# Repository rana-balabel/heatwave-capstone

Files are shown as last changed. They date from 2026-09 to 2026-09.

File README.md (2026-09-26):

# HeatWave 🔥

**AI-Powered Heatstroke Prediction Wearable**

University of Waterloo Engineering Capstone Design Project.

HeatWave is a wearable embedded system designed to assess heatstroke
risk using physiological and environmental sensor data.

## Capstone Poster

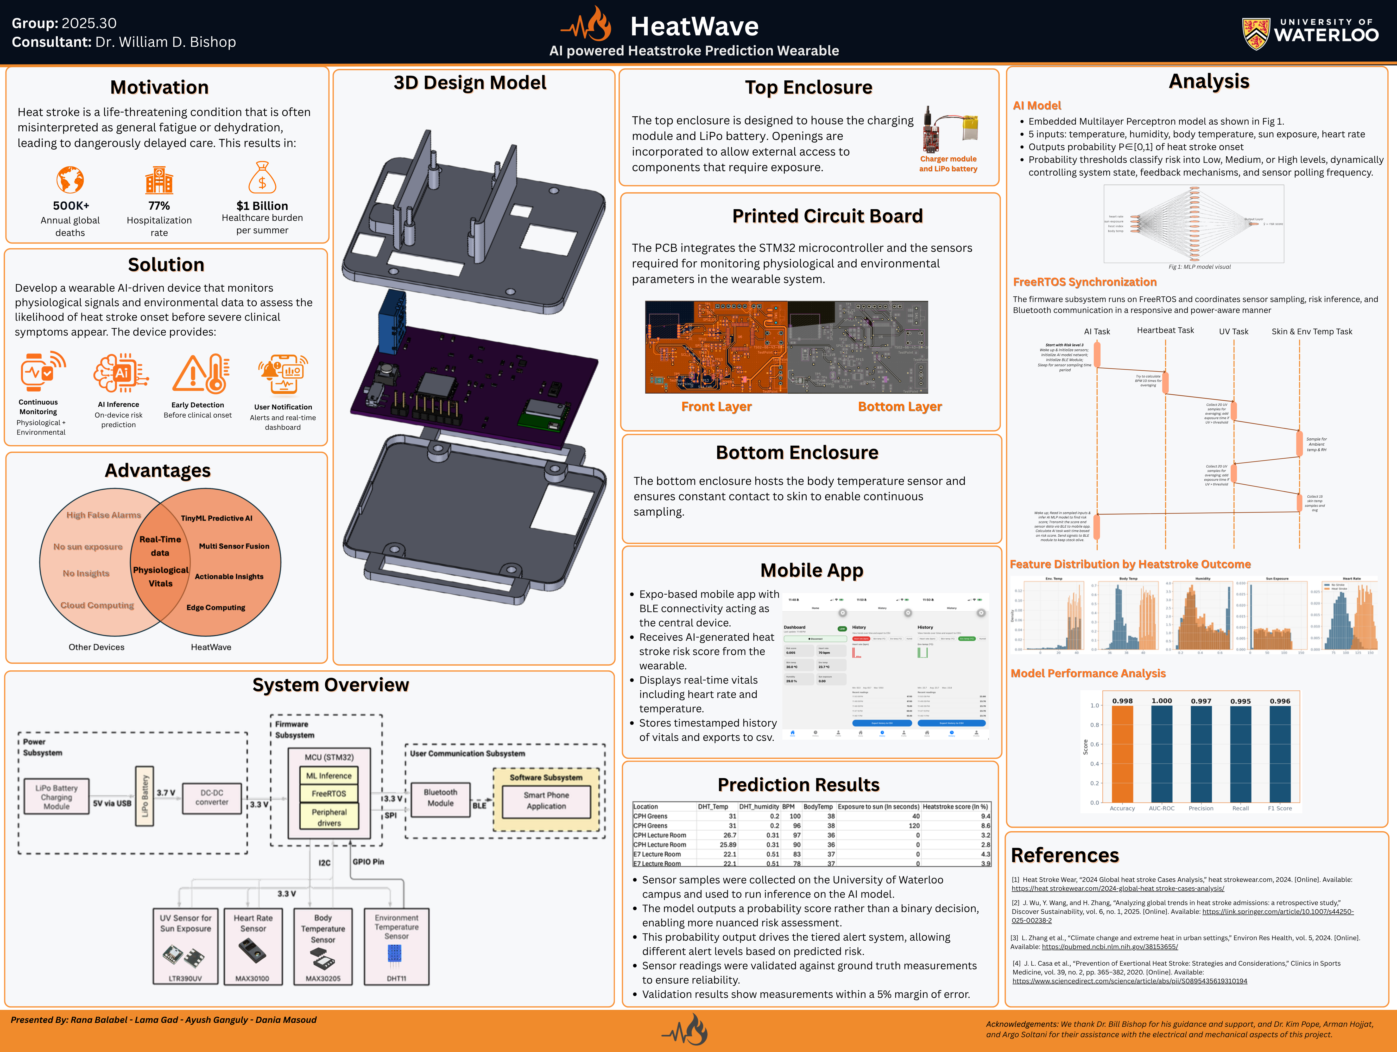
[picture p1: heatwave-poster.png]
HeatWave Capstone Poster


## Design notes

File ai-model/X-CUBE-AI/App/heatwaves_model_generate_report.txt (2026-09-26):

ST Edge AI Core v2.1.0-20201 42a90031b
Created date          : 2026-03-10 14:51:06
Parameters            : generate --target stm32f4 --name heatwaves_model -m /Users/ayushganguly/Documents/FYDP/heatwave/AI/heatwave_model_updated.tflite --compression none --verbosity 1 --workspace /var/folders/rd/5zstcb7s5693ycn6jp0glgjw0000gn/T/mxAI_workspace7943346606512414383834706467251366 --output /Users/ayushganguly/.stm32cubemx/heatwaves_model_output

Exec/report summary (generate)
---------------------------------------------------------------------------------------------------------------------------
model file         :   /Users/ayushganguly/Documents/FYDP/heatwave/AI/heatwave_model_updated.tflite                        
type               :   tflite                                                                                              
c_name             :   heatwaves_model                                                                                     
compression        :   none                                                                                                
options            :   allocate-inputs, allocate-outputs                                                                   
optimization       :   balanced                                                                                            
target/series      :   stm32f4                                                                                             
workspace dir      :   /var/folders/rd/5zstcb7s5693ycn6jp0glgjw0000gn/T/mxAI_workspace7943346606512414383834706467251366   
output dir         :   /Users/ayushganguly/.stm32cubemx/heatwaves_model_output                                             
model_fmt          :   float                                                                                               
model_name         :   heatwave_model_updated                                                                              
model_hash         :   0xe973620e0c79bc850783d2845456a136                                                                  
params #           :   71 items (284 B)                                                                                    
---------------------------------------------------------------------------------------------------------------------------
input 1/1          :   'serving_default_ke..tensor_320', f32(1x5), 20 Bytes, activations                                   
output 1/1         :   'nl_3', f32(1x1), 4 Bytes, activations                                                              
macc               :   181                                                                                                 
weights (ro)       :   284 B (284 B) (1 segment)                                                                           
activations (rw)   :   60 B (60 B) (1 segment) *                                                                           
ram (total)        :   60 B (60 B) = 60 + 0 + 0                                                                            
---------------------------------------------------------------------------------------------------------------------------
(*) 'input'/'output' buffers can be used from the activations buffer

Model name - heatwave_model_updated
------ ------------------------------------------------ ------------ ------------ ------ -------------------------------- --- --------------- -------------- --------------------- 
m_id   layer (type,original)                            oshape       param/size     macc                     connected to   | c_size          c_macc         c_type                
------ ------------------------------------------------ ------------ ------------ ------ -------------------------------- --- --------------- -------------- --------------------- 
0      serving_default_ke..tensor_320 (Input, )         [b:1,c:5]                                                           | +240(+100.0%)   +60(+100.0%)   Dense_[0]             
       sequential_8_1_den..6_1_MatMul (Placeholder, )   [b:10,c:5]   50/200                                                 | -200(-100.0%)                  
       sequential_8_1_den..VariableOp (Placeholder, )   [b:10]       10/40                                                  | -40(-100.0%)                   
       gemm_0 (Gemm, FULLY_CONNECTED)                   [b:1,c:10]                    60   serving_default_ke..tensor_320   |                 -60(-100.0%)   
                                                                                           sequential_8_1_den..6_1_MatMul   | 
                                                                                           sequential_8_1_den..VariableOp   | 
------ ------------------------------------------------ ------------ ------------ ------ -------------------------------- --- --------------- -------------- --------------------- 
1      nl_1 (Nonlinearity, LOGISTIC)                    [b:1,c:10]                   100                           gemm_0   |                                Nonlinearity_[1]      
------ ------------------------------------------------ ------------ ------------ ------ -------------------------------- --- --------------- -------------- --------------------- 
2      arith_constant (Placeholder, )                   [b:1,c:10]   10/40                                                  | +4(+10.0%)      +11(+100.0%)   Dense_[2]             
       arith_constant1 (Placeholder, )                  [b:1]        1/4                                                    | -4(-100.0%)                    
       gemm_2 (Gemm, FULLY_CONNECTED)                   [b:1,c:1]                     11                             nl_1   |                 -11(-100.0%)   
                                                                                                           arith_constant   | 
                                                                                                          arith_constant1   | 
------ ------------------------------------------------ ------------ ------------ ------ -------------------------------- --- --------------- -------------- --------------------- 
3      nl_3 (Nonlinearity, LOGISTIC)                    [b:1,c:1]                     10                           gemm_2   |                                Nonlinearity_[o][3]   
------ ------------------------------------------------ ------------ ------------ ------ -------------------------------- --- --------------- -------------- --------------------- 
model/c-model: macc=181/181  weights=284/284  activations=--/60 io=--/0

Generated C-graph summary
------------------------------------------------------------------------------------------------------------------------
model name            : heatwave_model_updated
c-name                : heatwaves_model
c-node #              : 4
c-array #             : 9
activations size      : 60 (1 segment)
weights size          : 284 (1 segment)
macc                  : 181
inputs                : ['serving_default_keras_tensor_320_output']
outputs               : ['nl_3_output']

C-Arrays (9)
------ ----------------------------------------- ----------- ------------------------- ------------- --------- 
c_id   name (*_array)                            item/size   domain/mem-pool           c-type        comment   
------ ----------------------------------------- ----------- ------------------------- ------------- --------- 
0      gemm_0_bias                               10/40       weights/weights           const float             
1      gemm_0_output                             10/40       activations/**default**   float                   
2      gemm_0_weights                            50/200      weights/weights           const float             
3      gemm_2_bias                               1/4         weights/weights           const float             
4      gemm_2_output                             1/4         activations/**default**   float                   
5      gemm_2_weights                            10/40       weights/weights           const float             
6      nl_1_output                               10/40       activations/**default**   float                   
7      nl_3_output                               1/4         activations/**default**   float         /output   
8      serving_default_keras_tensor_320_output   5/20        activations/**default**   float         /input    
------ ----------------------------------------- ----------- ------------------------- ------------- --------- 

C-Layers (4)
------ ---------------- ---- --------------- ------ ----- -------------------------------------------- ------------------ 
c_id   name (*_layer)   id   layer_type      macc   rom   tensors                                      shape (array id)   
------ ---------------- ---- --------------- ------ ----- -------------------------------------------- ------------------ 
0      gemm_0           0    Dense           60     240   I: serving_default_keras_tensor_320_output   f32(1x5) (8)       
                                                          W: gemm_0_weights                            f32(10x5) (2)      
                                                          W: gemm_0_bias                               f32(10) (0)        
                                                          O: gemm_0_output                             f32(1x10) (1)      
------ ---------------- ---- --------------- ------ ----- -------------------------------------------- ------------------ 
1      nl_1             1    Nonlinearity    100    0     I: gemm_0_output                             f32(1x10) (1)      
                                                          O: nl_1_output                               f32(1x10) (6)      
------ ---------------- ---- --------------- ------ ----- -------------------------------------------- ------------------ 
2      gemm_2           2    Dense           11     44    I: nl_1_output                               f32(1x10) (6)      
                                                          W: gemm_2_weights                            f32(1x10) (5)      
                                                          W: gemm_2_bias                               f32(1) (3)         
                                                          O: gemm_2_output                             f32(1x1) (4)       
------ ---------------- ---- --------------- ------ ----- -------------------------------------------- ------------------ 
3      nl_3             3    Nonlinearity    10     0     I: gemm_2_output                             f32(1x1) (4)       
                                                          O: nl_3_output                               f32(1x1) (7)       
------ ---------------- ---- --------------- ------ ----- -------------------------------------------- ------------------ 

Number of operations per c-layer
------- ------ --------------------- ----- -------------- 
c_id    m_id   name (type)             #op           type 
------- ------ --------------------- ----- -------------- 
0       0      gemm_0 (Dense)           60   smul_f32_f32 
1       1      nl_1 (Nonlinearity)     100     op_f32_f32 
2       2      gemm_2 (Dense)           11   smul_f32_f32 
3       3      nl_3 (Nonlinearity)      10     op_f32_f32 
------- ------ --------------------- ----- -------------- 
total                                  181 

Number of operation types
---------------- ----- ----------- 
operation type       #           % 
---------------- ----- ----------- 
smul_f32_f32        71       39.2% 
op_f32_f32         110       60.8% 

Complexity report (model)
------ ---------------------------------- ------------------------- ------------------------- ------ 
m_id   name                               c_macc                    c_rom                     c_id   
------ ---------------------------------- ------------------------- ------------------------- ------ 
0      serving_default_keras_tensor_320   ||||||||||        33.1%   ||||||||||||||||  84.5%   [0]    
1      nl_1                               ||||||||||||||||  55.2%   |                  0.0%   [1]    
2      arith_constant                     ||                 6.1%   |||               15.5%   [2]    
3      nl_3                               ||                 5.5%   |                  0.0%   [3]    
------ ---------------------------------- ------------------------- ------------------------- ------ 
macc=181 weights=284 act=60 ram_io=0
 
 Requested memory size by section - "stm32f4" target
 ------------------------------ ------- -------- ------- ----- 
 module                            text   rodata    data   bss 
 ------------------------------ ------- -------- ------- ----- 
 NetworkRuntime1010_CM4_GCC.a     6,052        0       0     0 
 heatwaves_model.o                  472       32   1,264   136 
 heatwaves_model_data.o              48       16      88     0 
 lib (toolchain)*                   614       24       0     0 
 ------------------------------ ------- -------- ------- ----- 
 RT total**                       7,186       72   1,352   136 
 ------------------------------ ------- -------- ------- ----- 
 weights                              0      288       0     0 
 activations                          0        0       0    60 
 io                                   0        0       0     0 
 ------------------------------ ------- -------- ------- ----- 
 TOTAL                            7,186      360   1,352   196 
 ------------------------------ ------- -------- ------- ----- 
 *  toolchain objects (libm/libgcc*)
 ** RT AI runtime objects (kernels+infrastructure)
  
  Summary - "stm32f4" target
  ---------------------------------------------------
               FLASH (ro)      %*   RAM (rw)       % 
  ---------------------------------------------------
  RT total          8,610   96.8%      1,488   96.1% 
  ---------------------------------------------------
  TOTAL             8,898              1,548         
  ---------------------------------------------------
  *  rt/total

Generated files (7)
--------------------------------------------------------------------------------------- 
/Users/ayushganguly/.stm32cubemx/heatwaves_model_output/heatwaves_model_data_params.h   
/Users/ayushganguly/.stm32cubemx/heatwaves_model_output/heatwaves_model_data_params.c   
/Users/ayushganguly/.stm32cubemx/heatwaves_model_output/heatwaves_model_data.h          
/Users/ayushganguly/.stm32cubemx/heatwaves_model_output/heatwaves_model_data.c          
/Users/ayushganguly/.stm32cubemx/heatwaves_model_output/heatwaves_model_config.h        
/Users/ayushganguly/.stm32cubemx/heatwaves_model_output/heatwaves_model.h               
/Users/ayushganguly/.stm32cubemx/heatwaves_model_output/heatwaves_model.c

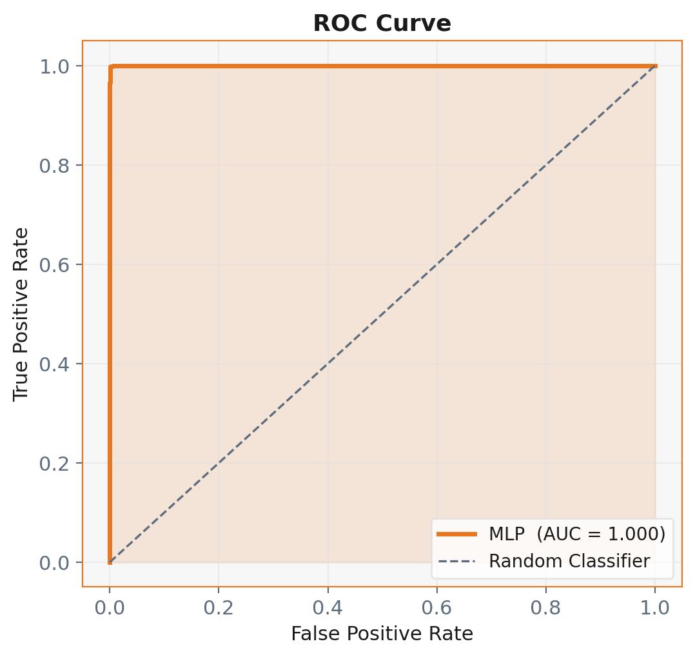
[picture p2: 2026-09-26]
AI/poster_figures/2_roc_curve.png

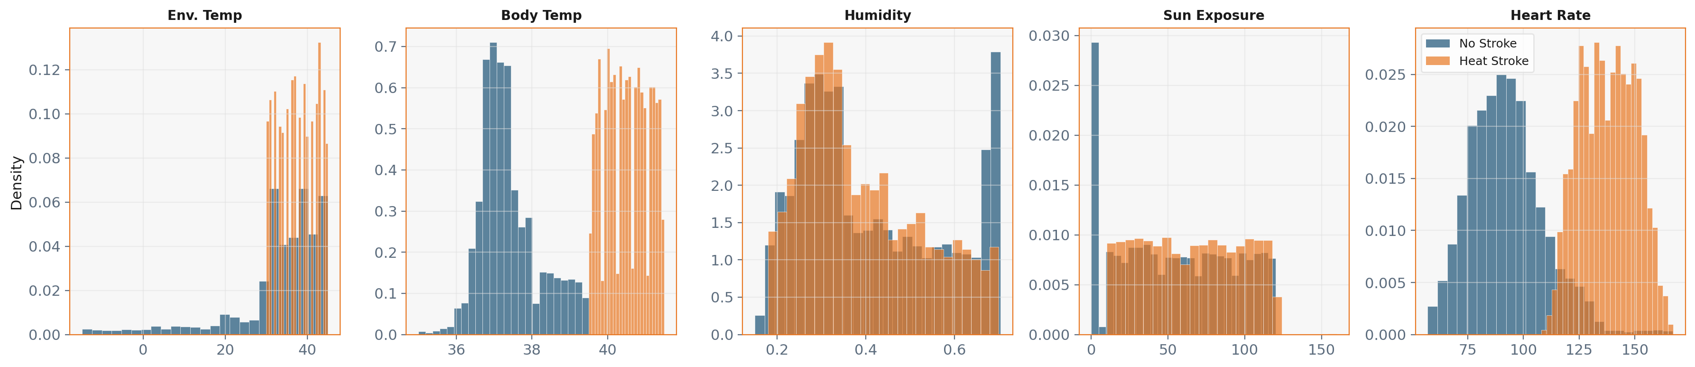
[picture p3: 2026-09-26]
AI/poster_figures/1_feature_distributions.png

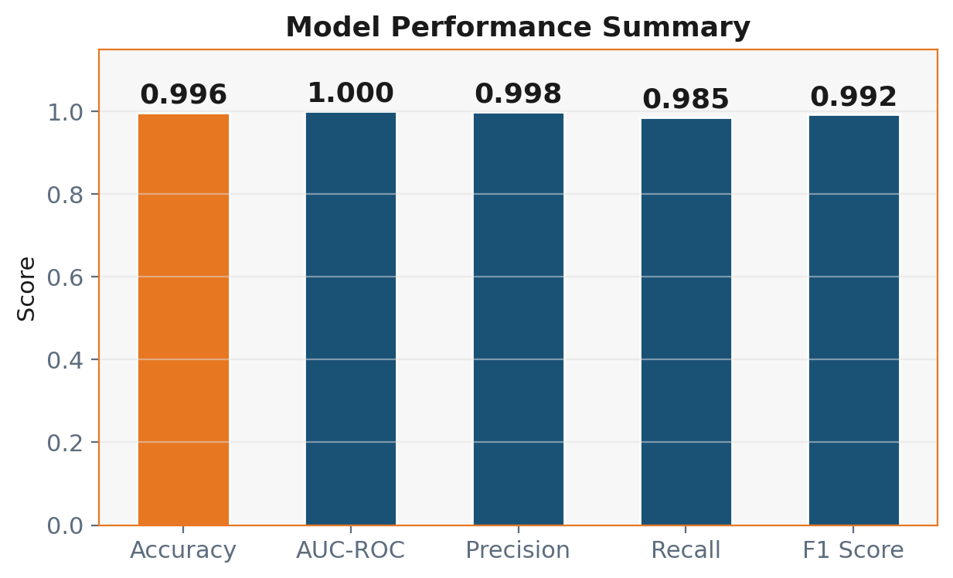
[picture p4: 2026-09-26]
AI/poster_figures/8_metrics_summary.png

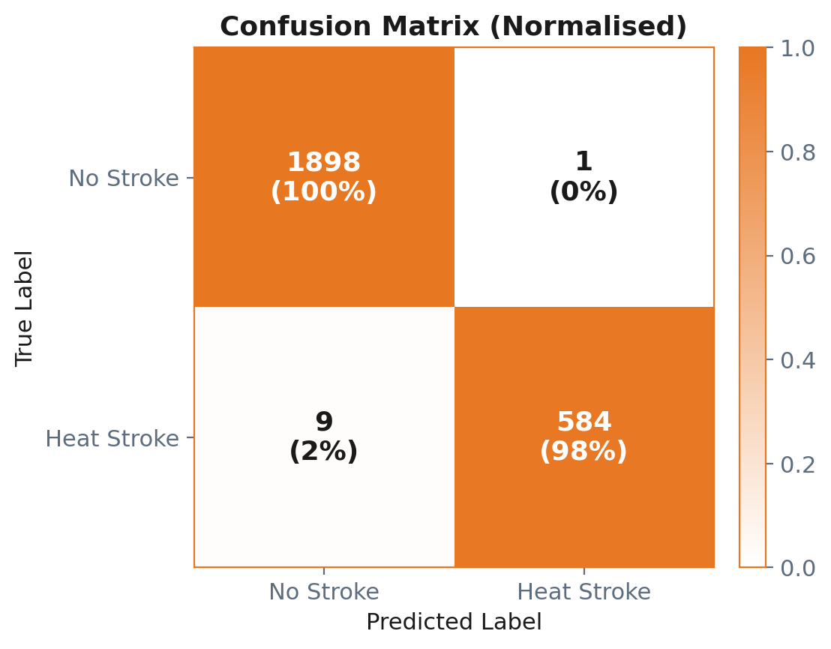
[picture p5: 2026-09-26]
AI/poster_figures/3_confusion_matrix.png

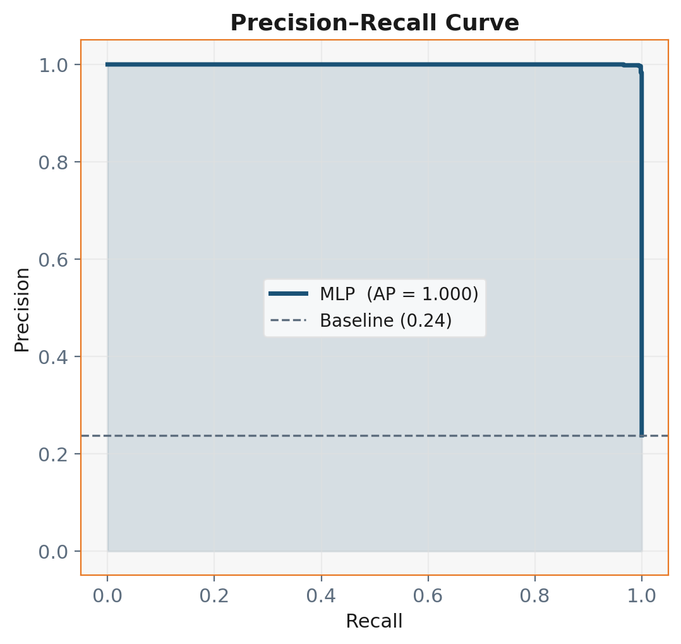
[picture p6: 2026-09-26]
AI/poster_figures/4_precision_recall.png

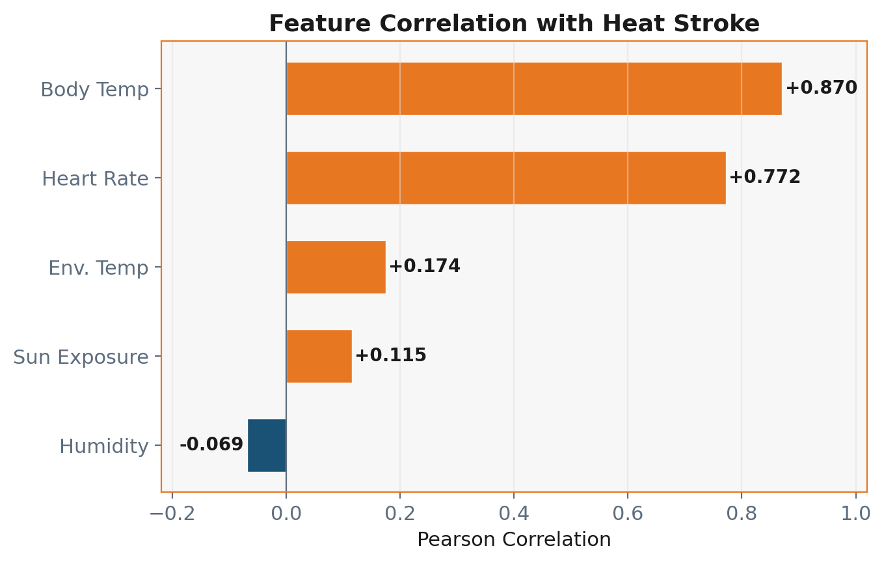
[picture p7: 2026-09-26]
AI/poster_figures/6_feature_correlation.png

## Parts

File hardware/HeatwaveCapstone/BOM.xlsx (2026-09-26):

Comment | Designator | Footprint | JLCPCB Part Number # | Quantity | MFR.Part # | Notes
0.1 micro farad | C5, C7, C9, C2, C20, C21, C22, C11, C13, C14, C16, C17, C18 | Capacitor_SMD:C_0603_1608Metric | C1590 | 13 | CL10B104KA8NNNC
4.7 micro farad | C10 | Capacitor_SMD:C_0603_1608Metric | C69335 | 1 | CL21A475KAQNNNE
2.2 micro farad unpolarized, 25V rated | C6 | Capacitor_SMD:C_0603_1608Metric | C57895 | 1 | 1206F225M250NT
10 pico farad unpolarized, 25V rated | C12, C15 | Capacitor_SMD:C_0603_1608Metric | C1853175 | 2 | CL10A225KA8NNNC
1 micro farad unpolarized, 25V rated | C19, C1, C4, C8 | Capacitor_SMD:C_0603_1608Metric | C5673 | 4 | C0603C104K3RACTU
22 micro farad (unpolarized) | C3 | Capacitor_SMD:C_0603_1608Metric | C84419 | 1 | GRM188R61A226ME15D | 10 V rated
4.7 kohm, 0.1% tolerance | R1, R3 | Resistor_SMD:R_0603_1608Metric | C186202 | 2 | RN73H1JTTD4701B25
2.2kohm | R12, R13, R15, R14 | Resistor_SMD:R_0603_1608Metric | C351660 | 4 | PTFR0603B2K20P9
200 kohm | R11 | Resistor_SMD:R_0603_1608Metric | C95331 | 1 | HoAR0805-1/8W-200KR-0.1%-TCR25
10kohm | R8, R10, R4, R5, R6, R7 | Resistor_SMD:R_0603_1608Metric | C15401 | 6 | HoAR0805-1/10W-10KR-0.1%-TCR5
5kohm | R2 | Resistor_SMD:R_0603_1608Metric | C862232 | 1 | RT0603BRE075KL
LED Surface Mount | D1 | LTST-C190KFKT:LEDM1608X80 | C157740 | 1 | LTST-C190KFKT
LDO 3.3V | U10 | XC6206P332MR-G:SOT-23 | C5446 | 1 | XC6206P332MR-G
Skin Temp Sensor | U1 | MAX30205MTA_:SON65P300X300X80-9N | C476171 | 1 | MAX30205MTA+T
Logic Level Shifter I2C | U9 | PCA9306DCTR:SOP65P400X130-8N | C123752 | 1 | PCA9306DCTR
UV Sensor | U5 | LTR390_FP:SMD6_LTR-390UV-01_LTO | C492374 | 1 | LTR-390UV-01
Logic Level Shifter 1.8V | U3 | DBV0005A_N:SOT95P280X145-5N | C2877701 | 1 | TPS70918QDBVRQ1
SW_SPDT | SW1 | Button_Switch_SMD:SW_SPDT_CK_JS102011SAQN | C221660 | 1 | JS102011SAQN
SW_SPST | S2 | B3F-1000:SW_B3F-1000 | C93157 | 1 | B3F-1000
Oscillator | Y1 Crystal_GND24 | ABM8-16:XTAL_ABM8-16.000MHZ-10-1-U-T | C1986553 | 1 | ABM8-16.000MHZ-10-1-U-T
MCU | U6 | Package_QFP:LQFP-64_10x10mm_P0.5mm | C116978 | 1 | STM32F401RET6
BLE Module | U7 | BLUENRG-M0A:XCVR_BLUENRG-M0A | C2969936 | 1 | BLUENRG-M0A
New BOM
10kohm | R8, R10, R4, R5, R6, R7 | Resistor_SMD:R_0603_1608Metric | RC0603FR-0710KL
4.7 micro farad | C10 | Capacitor_SMD:C_0603_1608Metric | CL10A475KA8NQNC
1 microF | C19, C1, C4, C8 | Capacitor_SMD:C_0603_1608Metric | CL10105KL8NNNC
200 kohm | R11 | Resistor_SMD:R_0603_1608Metric | RC0603FR-07200KL
4.7 kohm | R1 | Resistor_SMD:R_0603_1608Metric | RN73H1JTTD4701B25
HeartBeat Sensor | U2 | MAX30100EFD_:LGA14R80P2X7_560X280X130 | MAX30100EFD+T
Body Temp Sensor | U1 | MAX30205MTA_:SON65P300X300X80-9N | MAX30205MTA+T
0.1 micro farad | C5 | Capacitor_SMD:C_0603_1608Metric | CL10B104KA8NNNC

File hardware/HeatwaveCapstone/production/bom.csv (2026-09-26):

Designator | Footprint | Quantity | Value | LCSC Part #
C1, C19 | 0603 | 2 | 1u
C10 | 0603 | 1 | 4.7u
C11, C13, C14, C16, C17, C18, C20 | 0603 | 7 | 100n
C12, C15 | 0603 | 2 | 10p
C2, C21, C22, C5, C7, C9 | 0603 | 6 | 0.1u
C3 | 0603 | 1 | 22u
C4, C8 | 0603 | 2 | 1uF
C6 | 0603 | 1 | 2.2u
D1 | LEDM1608X80 | 1 | LTST-C190KFKT
J1 | PinHeader_1x02_P2.54mm_Vertical | 1 | Conn_01x02_Pin
J2 | PinHeader_1x06_P2.54mm_Vertical | 1 | Conn_01x06_Pin
R1, R3 | 0603 | 2 | 4.7k
R10, R4, R5, R6, R7, R8 | 0603 | 6 | 10k
R11 | 0603 | 1 | 200k
R12, R13, R14, R15 | 0603 | 4 | 2.2k
R2 | 0603 | 1 | 1k5
S2 | SW_B3F-1000 | 1 | TS02-66-43-BK-160-SCR-D
SW1 | SW_SPDT_CK_JS102011SAQN | 1 | SW_SPDT
TP1, TP6 | TestPoint_Pad_1.0x1.0mm | 2 | SPI2_CS
TP10 | TestPoint_Pad_1.0x1.0mm | 1 | SPI2_IRQ
TP13 | TestPoint_Pad_1.0x1.0mm | 1 | SDA_1V8
TP14 | TestPoint_Pad_1.0x1.0mm | 1 | SCL_1V8
TP15 | TestPoint_Pad_1.0x1.0mm | 1 | 1v8
TP16 | TestPoint_Pad_1.0x1.0mm | 1 | IN_3v3
TP1_GND1, TP20, TP2_5V_1, TP4, TP5 | TestPoint_Pad_1.0x1.0mm | 5 | TestPoint
TP3_3V3 | TestPoint_Pad_1.0x1.0mm | 1 | ~
TP7 | TestPoint_Pad_1.0x1.0mm | 1 | SPI2_CLK
TP8 | TestPoint_Pad_1.0x1.0mm | 1 | SPI2_MOSI
TP9 | TestPoint_Pad_1.0x1.0mm | 1 | SPI2_MISO
U1 | SON65P300X300X80-9N | 1 | MAX30205
U10 | SOT-23 | 1 | XC6206P332MR-G | XC6206P332MR-G
U2 | LGA14R80P2X7_560X280X130 | 1 | MAX30100EFDT
U3 | SOT95P280X145-5N | 1 | TPS70918QDBVRQ1
U5 | SMD6_LTR-390UV-01_LTO | 1 | LTR-390UV-01
U6 | LQFP-64_10x10mm_P0.5mm | 1 | STM32F401RETx
U7 | XCVR_BLUENRG-M0A | 1 | BLUENRG-M0A
U8 | Aosong_DHT11_5.5x12.0_P2.54mm | 1 | DHT11
U9 | SOP65P400X130-8N | 1 | PCA9306
Y1 | XTAL_ABM8-16.000MHZ-10-1-U-T | 1 | Crystal_GND24

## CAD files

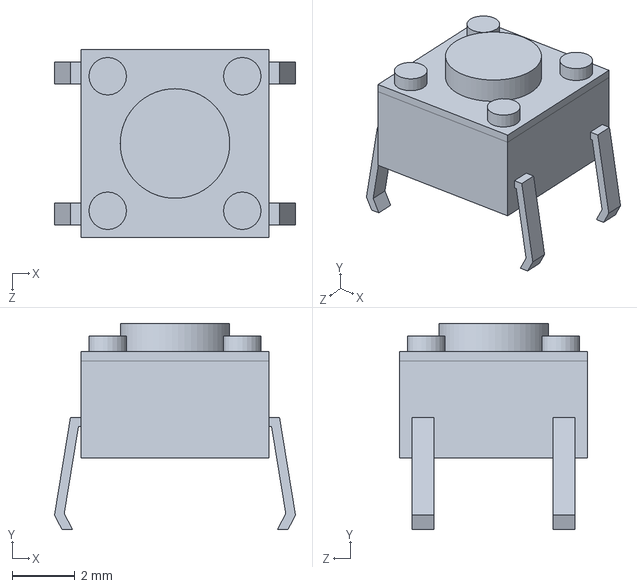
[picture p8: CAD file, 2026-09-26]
mechanical/B3F-1000--3DModel-STEP-418109.SLDPRT
7.70 x 6.59 x 6.00 mm

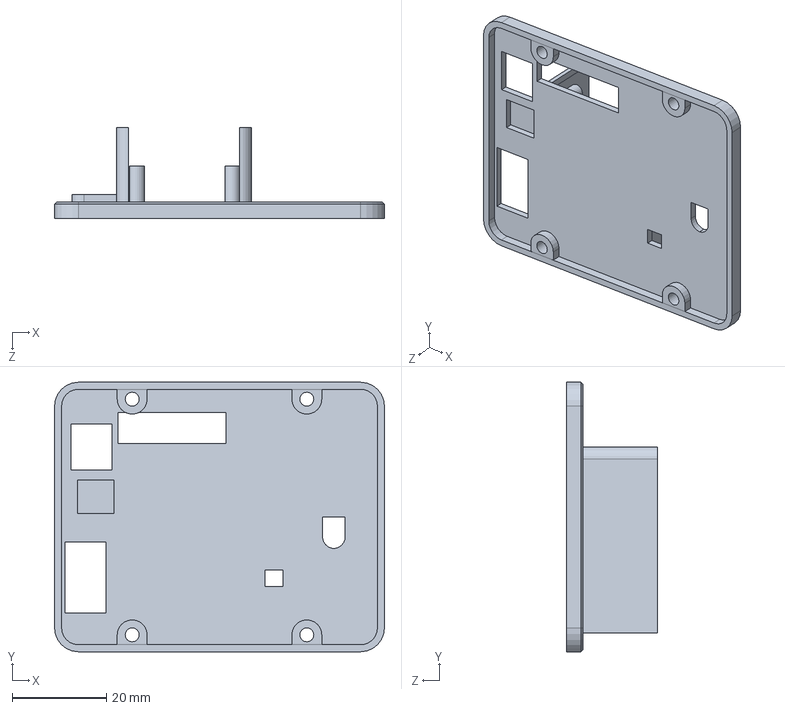
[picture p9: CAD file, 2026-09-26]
mechanical/top_enclosure_part.SLDPRT
70.0 x 57.1 x 19.3 mm

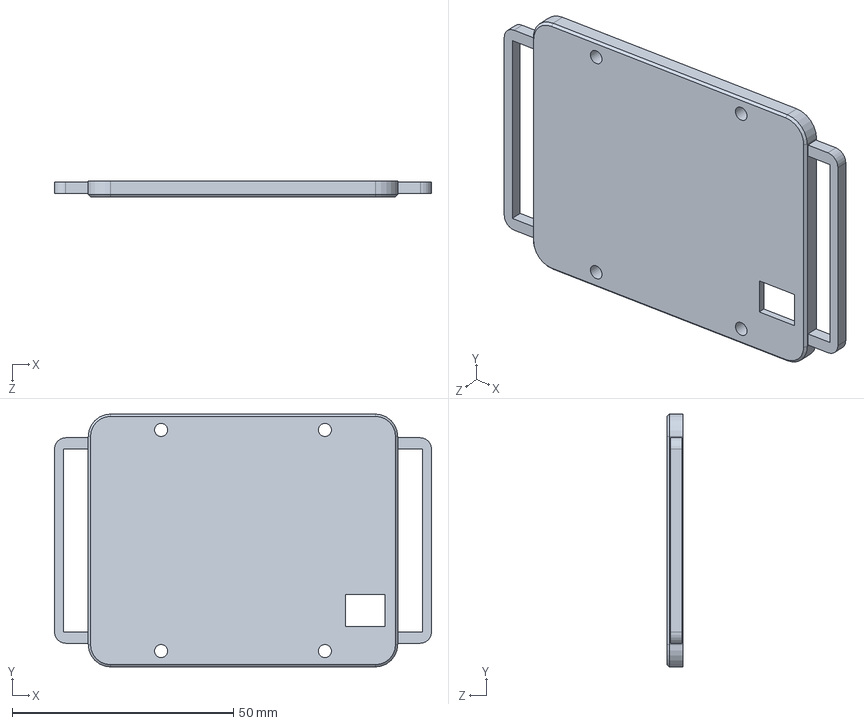
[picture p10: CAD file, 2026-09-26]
mechanical/botton_enclosure_part.SLDPRT
85.2 x 57.1 x 3.56 mm

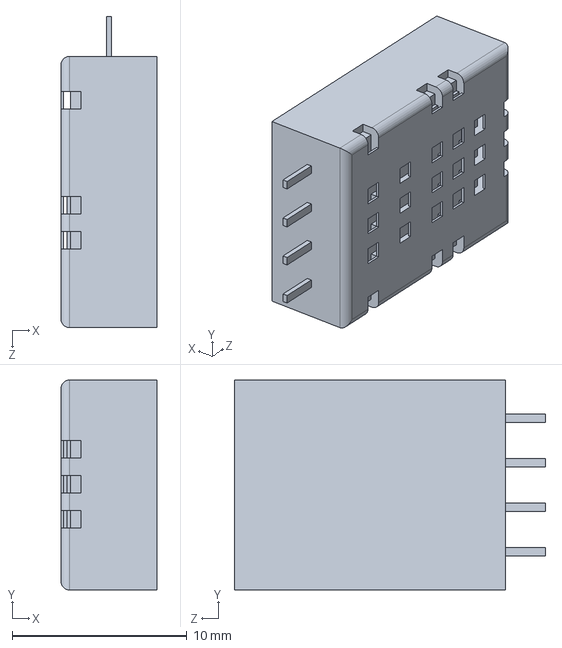
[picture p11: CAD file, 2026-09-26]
mechanical/Aosong_DHT11_5.5x12.0_P2.54mm.SLDPRT
5.50 x 12.0 x 17.8 mm

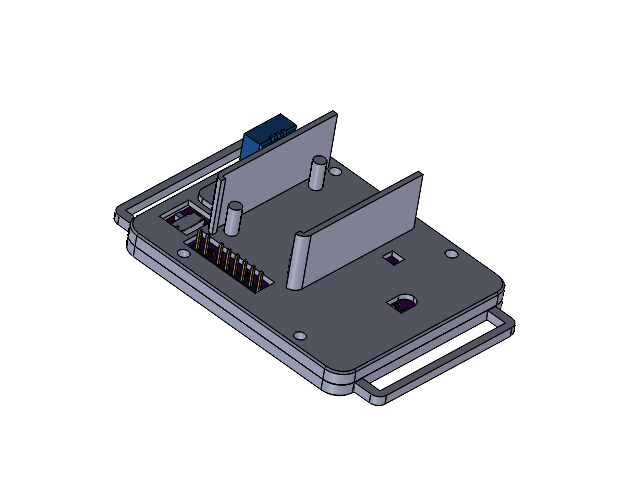
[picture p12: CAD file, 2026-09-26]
mechanical/HeatwaveCapstone.SLDASM
MAX6496ATA+T_MAX6496ATA+T
C_0603_1608Metric x 22
R_0603_1608Metric x 14
Aosong_DHT11_5.5x12.0_P2.54mm
PinHeader_1x06_P2.54mm_Vertical
B3F-1000--3DModel-STEP-418109
MAX30100EFD+T--3DModel-STEP-510211
JS102011SAQN--3DModel-Eagle-1
LQFP-64_10x10mm_P0.5mm
BLUENRG-M0A
PinHeader_1x02_P2.54mm_Vertical
SMD6_LTR-390UV-01_LTO
HeatwaveCapstone_PCB
botton_enclosure_part
top_enclosure_part

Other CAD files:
mechanical/LQFP-64_10x10mm_P0.5mm.SLDPRT
mechanical/BLUENRG-M0A.SLDPRT
mechanical/MAX6496ATA+T_MAX6496ATA+T.SLDPRT
mechanical/SMD6_LTR-390UV-01_LTO.SLDPRT
mechanical/R_0603_1608Metric.SLDPRT
mechanical/PinHeader_1x02_P2.54mm_Vertical.SLDPRT
mechanical/PinHeader_1x06_P2.54mm_Vertical.SLDPRT
mechanical/HeatwaveCapstone_PCB.SLDPRT
mechanical/C_0603_1608Metric.SLDPRT
mechanical/MAX30205MTA+T.SLDASM
mechanical/JS102011SAQN--3DModel-Eagle-1.SLDPRT
mechanical/MAX30100EFD+T--3DModel-STEP-510211.SLDPRT

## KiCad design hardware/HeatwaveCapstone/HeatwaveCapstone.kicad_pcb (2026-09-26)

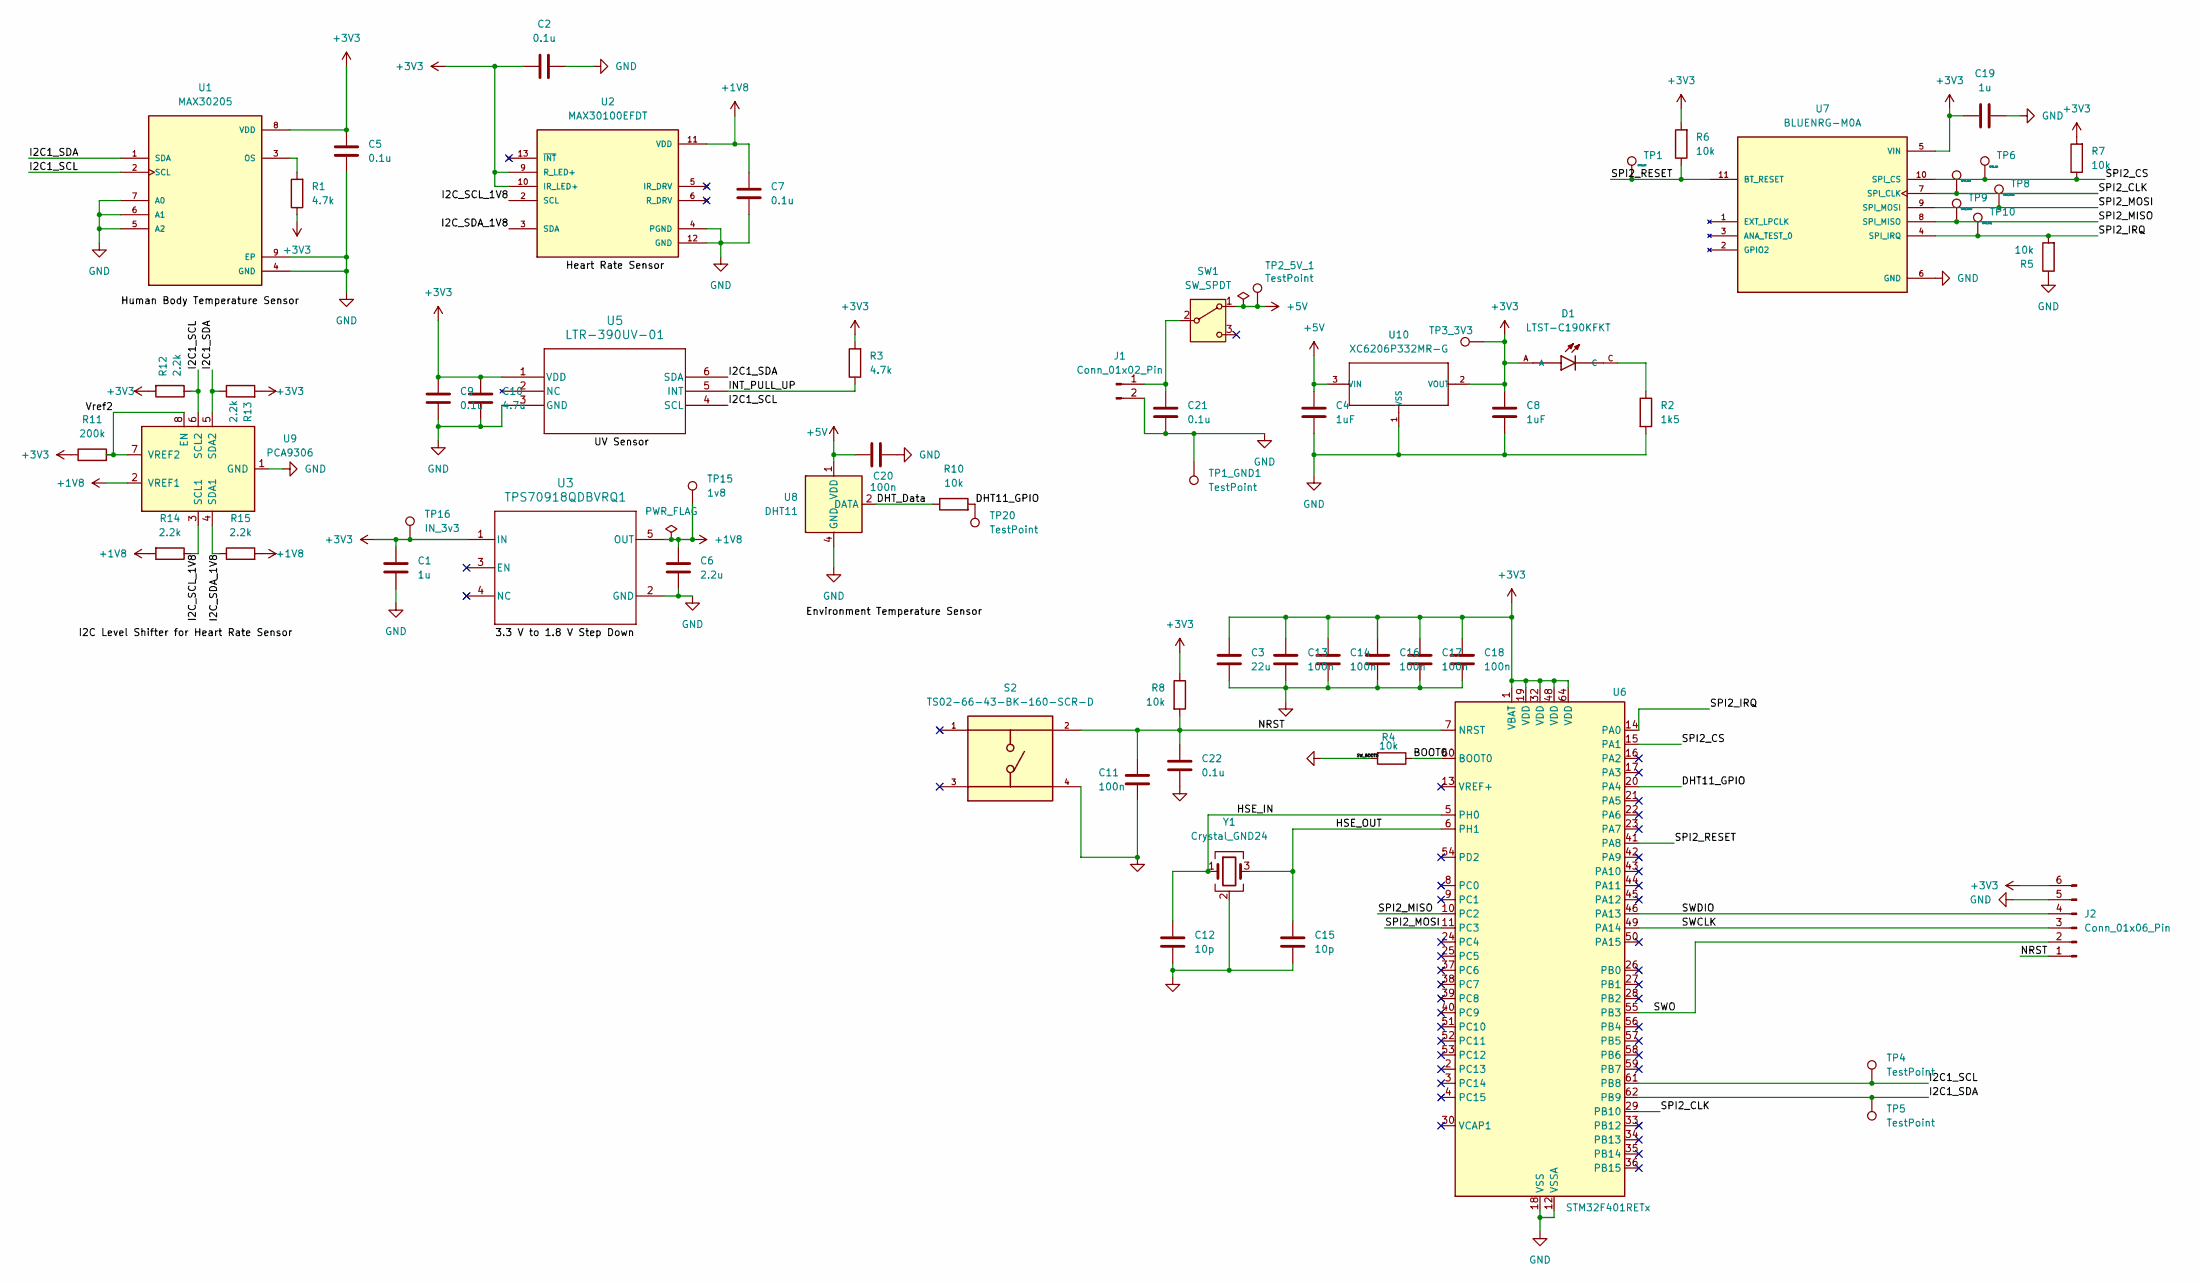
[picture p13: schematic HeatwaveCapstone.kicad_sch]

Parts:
C1, C19: 1u; C_0603_1608Metric
C2, C5, C7, C9, C21, C22: 0.1u; C_0603_1608Metric
C3: 22u; C_0603_1608Metric
C4, C8: 1uF; C_0603_1608Metric
C6: 2.2u; C_0603_1608Metric
C10: 4.7u; C_0603_1608Metric
C11, C13, C14, C16, C17, C18, C20: 100n; C_0603_1608Metric
C12, C15: 10p; C_0603_1608Metric
D1: LTST-C190KFKT; LEDM1608X80
J1: Conn_01x02_Pin; PinHeader_1x02_P2.54mm_Vertical
J2: Conn_01x06_Pin; PinHeader_1x06_P2.54mm_Vertical
R1, R3: 4.7k; R_0603_1608Metric
R2: 1k5; R_0603_1608Metric
R4, R5, R6, R7, R8, R10: 10k; R_0603_1608Metric
R11: 200k; R_0603_1608Metric
R12, R13, R14, R15: 2.2k; R_0603_1608Metric
S2: TS02-66-43-BK-160-SCR-D; SW_B3F-1000; PARTREV 1.0
SW1: SW_SPDT; SW_SPDT_CK_JS102011SAQN
TP1, TP6: SPI2_CS; TestPoint_Pad_1.0x1.0mm
TP1_GND1, TP2_5V_1, TP4, TP5, TP20: TestPoint; TestPoint_Pad_1.0x1.0mm
TP3_3V3: TestPoint_Pad_1.0x1.0mm
TP7: SPI2_CLK; TestPoint_Pad_1.0x1.0mm
TP8: SPI2_MOSI; TestPoint_Pad_1.0x1.0mm
TP9: SPI2_MISO; TestPoint_Pad_1.0x1.0mm
TP10: SPI2_IRQ; TestPoint_Pad_1.0x1.0mm
TP15: 1v8; TestPoint_Pad_1.0x1.0mm
TP16: IN_3v3; TestPoint_Pad_1.0x1.0mm
U1: MAX30205; SON65P300X300X80-9N
U2: MAX30100EFDT; LGA14R80P2X7_560X280X130
U3: TPS70918QDBVRQ1; SOT95P280X145-5N
U5: LTR-390UV-01; SMD6_LTR-390UV-01_LTO
U6: STM32F401RETx; LQFP-64_10x10mm_P0.5mm
U7: BLUENRG-M0A; XCVR_BLUENRG-M0A; PARTREV Rev 5
U8: DHT11; Aosong_DHT11_5.5x12.0_P2.54mm
U9: PCA9306; SOP65P400X130-8N
U10: XC6206P332MR-G; SOT-23; MPN XC6206P332MR-G
Y1: Crystal_GND24; XTAL_ABM8-16.000MHZ-10-1-U-T

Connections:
+1V8: C6.1, C7.1, R14.2, R15.2, TP15.1, U2.11 (VDD), U3.5 (OUT), U9.2 (VREF1)
+3V3: C1.1, C2.1, C3.1, C5.1, C8.1, C9.1, C10.1, C13.1, C14.1, C16.1, C17.1, C18.1, C19.1, D1.A, J2.6, R1.1, R3.2, R6.2, R7.2, R8.1, R11.1, R12.2, R13.2, TP3_3V3.1, TP16.1, U1.8 (VDD), U2.9 (R_LED+), U2.10 (IR_LED+), U3.1 (IN), U5.1 (VDD), U6.1 (VBAT), U6.19 (VDD), U6.32 (VDD), U6.48 (VDD), U6.64 (VDD), U7.5 (VIN), U10.2 (VOUT)
+5V: C4.1, C20.1, SW1.1 (A), TP2_5V_1.1, U8.1 (VDD), U10.3 (VIN)
/BOOT0: R4.1, U6.60 (BOOT0)
/DHT11_GPIO: R10.2, TP20.1, U6.20 (PA4)
/DHT_Data: R10.1, U8.2 (DATA)
/HSE_IN: C12.1, U6.5 (PH0), Y1.1
/HSE_OUT: C15.1, U6.6 (PH1), Y1.3
/I2C1_SCL: R12.1, TP4.1, U1.2 (SCL), U5.4 (SCL), U6.61 (PB8), U9.6 (SCL2)
/I2C1_SDA: R13.1, TP5.1, U1.1 (SDA), U5.6 (SDA), U6.62 (PB9), U9.5 (SDA2)
/I2C_SCL_1V8: R14.1, U2.2 (SCL), U9.3 (SCL1); also elsewhere on the board
/I2C_SDA_1V8: R15.1, U2.3 (SDA), U9.4 (SDA1); also elsewhere on the board
/INT_PULL_UP: R3.1, U5.5 (INT)
/NRST: C11.1, C22.2, J2.1, R8.2, S2.2, U6.7 (NRST)
/SPI2_CLK: TP7.1, U6.29 (PB10), U7.7 (SPI_CLK)
/SPI2_CS: R7.1, TP6.1, U6.15 (PA1), U7.10 (SPI_CS)
/SPI2_IRQ: R5.2, TP10.1, U6.14 (PA0), U7.4 (SPI_IRQ)
/SPI2_MISO: TP9.1, U6.10 (PC2), U7.8 (SPI_MISO)
/SPI2_MOSI: TP8.1, U6.11 (PC3), U7.9 (SPI_MOSI)
/SPI2_RESET: R6.1, TP1.1, U6.41 (PA8), U7.11 (BT_RESET)
/SWCLK: J2.3, U6.49 (PA14)
/SWDIO: J2.4, U6.46 (PA13)
/SWO: J2.2, U6.55 (PB3)
/Vref2: R11.2, U9.7 (VREF2), U9.8 (EN)
GND: C1.2, C2.2, C3.2, C4.2, C5.2, C6.2, C7.2, C8.2, C9.2, C10.2, C11.2, C12.2, C13.2, C14.2, C15.2, C16.2, C17.2, C18.2, C19.2, C20.2, C21.2, C22.1, J1.2, J2.5, R2.2, R4.2, R5.1, S2.4, TP1_GND1.1, U1.4 (GND), U1.5 (A2), U1.6 (A1), U1.7 (A0), U1.9 (EP), U2.4 (PGND), U2.12 (GND), U3.2 (GND), U5.3 (GND), U6.12 (VSSA), U6.18 (VSS), U6.31 (VSS), U6.47 (VSS), U6.63 (VSS), U7.6 (GND), U8.4 (GND), U9.1 (GND), U10.1 (VSS), Y1.2 (G), Y1.4 (G)
unnamed: D1.C, R2.1
unnamed: C21.1, J1.1, SW1.2 (B)
unnamed: R1.2, U1.3 (OS)

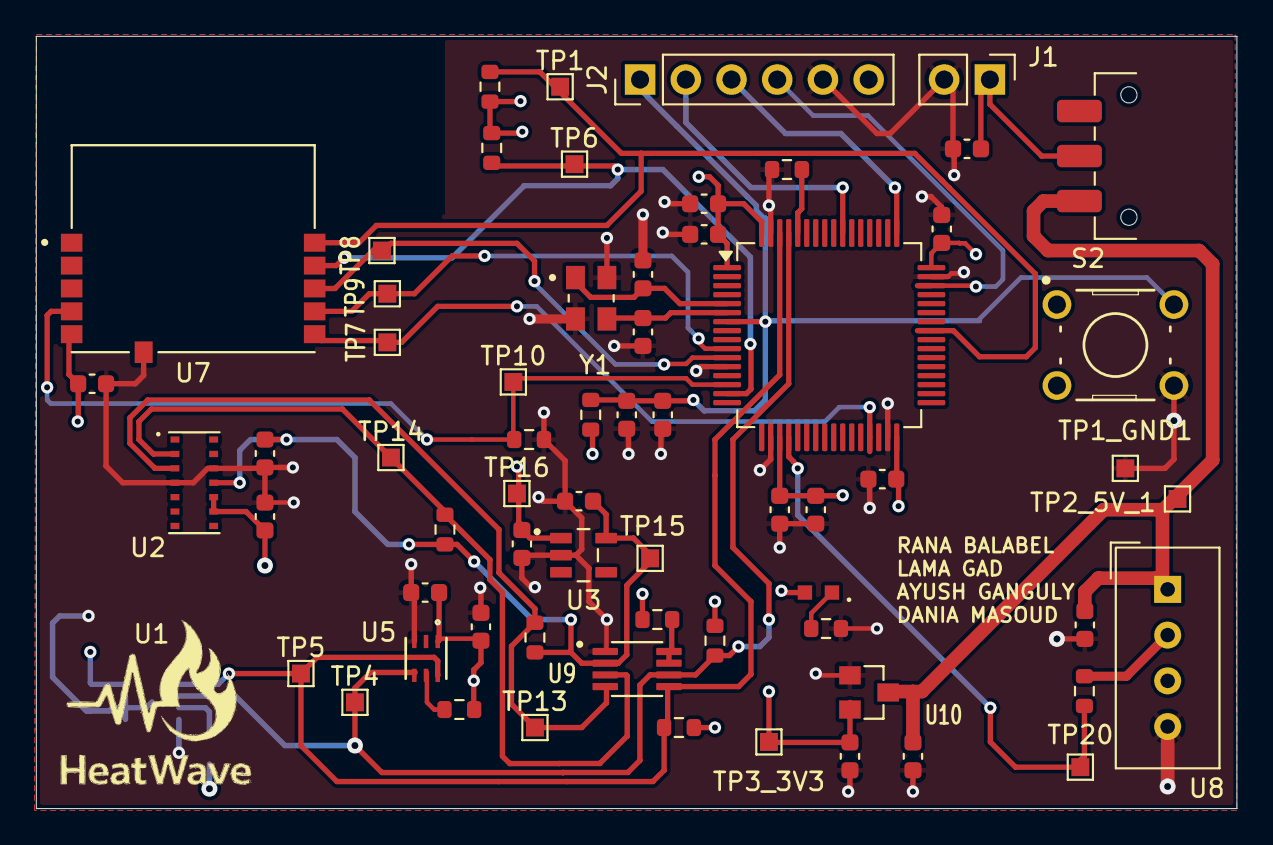
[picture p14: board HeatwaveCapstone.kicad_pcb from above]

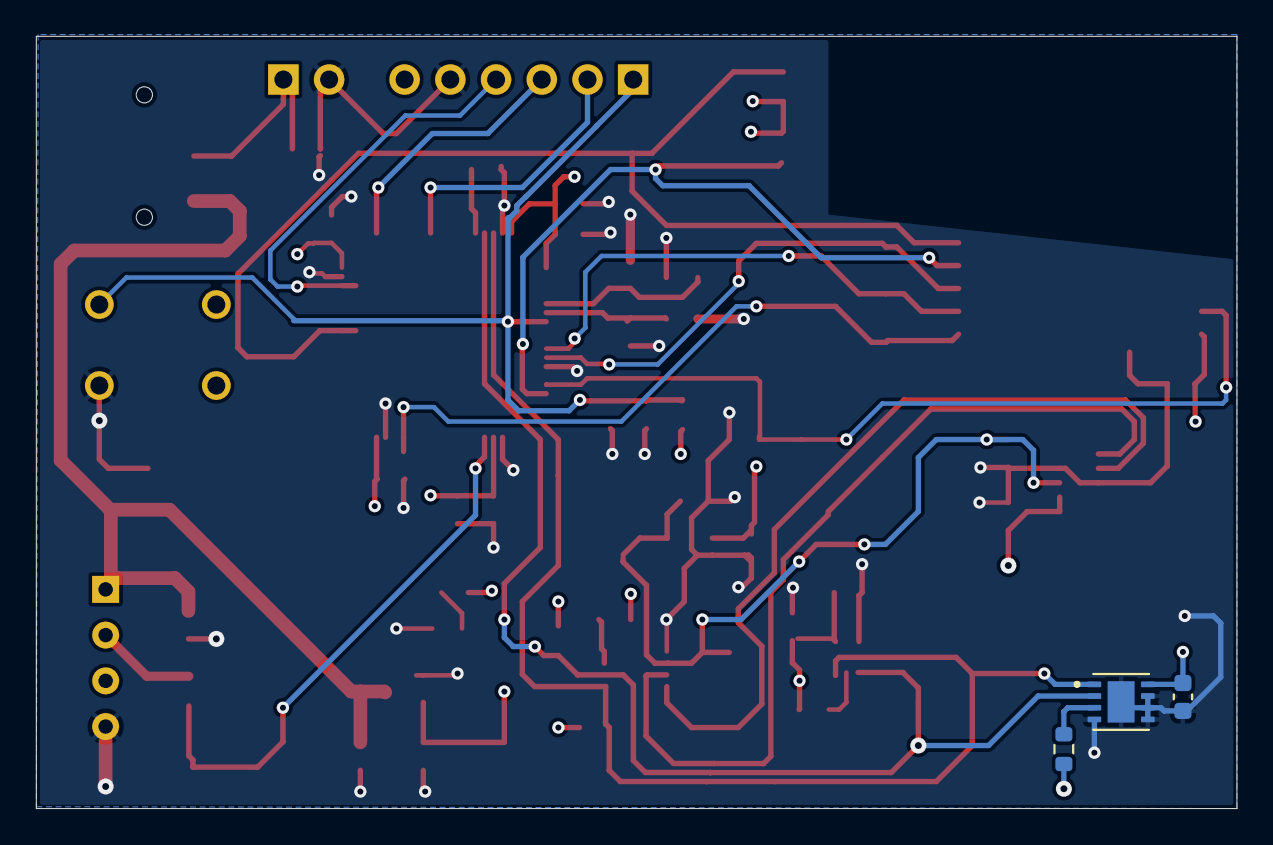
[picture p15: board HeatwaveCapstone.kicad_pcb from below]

Board: 4 copper layers, 66.7 x 42.9 mm, 67 parts (3 on the bottom side), 28 nets.

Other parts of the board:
TP13: SDA_1V8; TestPoint_Pad_1.0x1.0mm
TP14: SCL_1V8; TestPoint_Pad_1.0x1.0mm

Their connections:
/I2C_SCL_1V8: TP14.1; also elsewhere on the board
/I2C_SDA_1V8: TP13.1; also elsewhere on the board

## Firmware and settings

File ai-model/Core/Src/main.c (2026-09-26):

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
/* Includes ------------------------------------------------------------------*/
#include "main.h"
#include "cmsis_os.h"

/* USER CODE BEGIN Includes */
#include <stdio.h>

#include "RTOSTasks.h"

#include "ai_datatypes_defines.h"
#include "ai_platform.h"
#include "heatwaves_model.h"
#include "heatwaves_model_data.h"

/* USER CODE END Includes */

I2C_HandleTypeDef hi2c1;

SPI_HandleTypeDef hspi2;

TIM_HandleTypeDef htim11;

UART_HandleTypeDef huart2;

/* Definitions for defaultTask */
osThreadId_t defaultTaskHandle;
const osThreadAttr_t defaultTask_attributes = {
  .name = "defaultTask",
  .stack_size = 128 * 4,
  .priority = (osPriority_t) osPriorityNormal,
};
/* USER CODE BEGIN PV */
void microDelay(uint16_t delay)
{
  taskENTER_CRITICAL();
  __HAL_TIM_SET_COUNTER(&htim11, 0);
  while (__HAL_TIM_GET_COUNTER(&htim11) < delay)
    ;
  taskEXIT_CRITICAL();
}

/* USER CODE END PV */

void SystemClock_Config(void);
static void MX_GPIO_Init(void);
static void MX_USART2_UART_Init(void);
static void MX_TIM11_Init(void);
static void MX_I2C1_Init(void);
static void MX_SPI2_Init(void);
void StartDefaultTask(void *argument);

/* USER CODE BEGIN PFP */
// int _write(int file, char *ptr, int len)
// {
//   (void)file;
//   int DataIdx;

//   for (DataIdx = 0; DataIdx < len; DataIdx++)
//   {
//     ITM_SendChar(*ptr++);
//   }
//   return len;
// }

int _write(int file, char *ptr, int len)
{
  for (int i = 0; i < len; i++)
  {
    ITM_SendChar((*ptr++));
  }
  return len;
}

int __io_putchar(int ch)
{
  HAL_UART_Transmit(&huart2, &ch, 1, HAL_MAX_DELAY);
  return ch;
}

/* USER CODE END PFP */

/**
  * @brief  The application entry point.
  * @retval int
  */
int main(void)
{

  /* MCU Configuration--------------------------------------------------------*/

  /* Reset of all peripherals, Initializes the Flash interface and the Systick. */
  HAL_Init();

  /* Configure the system clock */
  SystemClock_Config();

  /* Initialize all configured peripherals */
  MX_GPIO_Init();
  MX_USART2_UART_Init();
  MX_TIM11_Init();
  MX_I2C1_Init();
  MX_SPI2_Init();
  /* USER CODE BEGIN 2 */
  HAL_TIM_Base_Start(&htim11);
  /* USER CODE END 2 */

  /* Init scheduler */
  osKernelInitialize();

  /* USER CODE BEGIN RTOS_MUTEX */
  /* add mutexes, ... */
  /* USER CODE END RTOS_MUTEX */

  /* USER CODE BEGIN RTOS_SEMAPHORES */
  /* add semaphores, ... */
  /* USER CODE END RTOS_SEMAPHORES */

  /* USER CODE BEGIN RTOS_TIMERS */
  /* start timers, add new ones, ... */
  /* USER CODE END RTOS_TIMERS */

  /* USER CODE BEGIN RTOS_QUEUES */
  /* add queues, ... */
  /* USER CODE END RTOS_QUEUES */

  /* Create the thread(s) */
  /* creation of defaultTask */
  defaultTaskHandle = osThreadNew(StartDefaultTask, NULL, &defaultTask_attributes);

  /* USER CODE BEGIN RTOS_THREADS */
  heatSkinTempTaskHandle = osThreadNew(StartSkinTempHeat, NULL, &heatSkinTemp_attributes);
  max30100TaskHandle = osThreadNew(StartMAX30100Task, NULL, &max30100Task_attributes);
  uvIndexTaskHandle = osThreadNew(StartLTR390Task, NULL, &uvIndexTask_attributes);
  AITaskHandle = osThreadNew(StartAITask, NULL, &AITaskHandle_attributes);
  /* USER CODE END RTOS_THREADS */

  /* USER CODE BEGIN RTOS_EVENTS */
  /* add events, ... */
  /* USER CODE END RTOS_EVENTS */

  /* Start scheduler */
  osKernelStart();

  /* We should never get here as control is now taken by the scheduler */

  /* Infinite loop */
  /* USER CODE BEGIN WHILE */
  while (1)
  {
    /* USER CODE END WHILE */

    /* USER CODE BEGIN 3 */
  }
  /* USER CODE END 3 */
}

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
/* USER CODE BEGIN Header_StartDefaultTask */
/**
 * @brief  Function implementing the defaultTask thread.
 * @param  argument: Not used
 * @retval None
 */
/* USER CODE END Header_StartDefaultTask */
void StartDefaultTask(void *argument)
{
  /* USER CODE BEGIN 5 */
  /* Infinite loop */
  for (;;)
  {

    osDelay(1);
  }
  /* USER CODE END 5 */
}

/**
  * @brief  This function is executed in case of error occurrence.
  * @retval None
  */
void Error_Handler(void)
{
  /* USER CODE BEGIN Error_Handler_Debug */
  /* User can add his own implementation to report the HAL error return state */
  __disable_irq();
  while (1)
  {
  }
  /* USER CODE END Error_Handler_Debug */
}
#ifdef USE_FULL_ASSERT
/**
  * @brief  Reports the name of the source file and the source line number
  *         where the assert_param error has occurred.
  * @param  file: pointer to the source file name
  * @param  line: assert_param error line source number
  * @retval None
  */
void assert_failed(uint8_t *file, uint32_t line)
{
  /* USER CODE BEGIN 6 */
  /* User can add his own implementation to report the file name and line number,
     ex: printf("Wrong parameters value: file %s on line %d\r\n", file, line) */
  /* USER CODE END 6 */
}
#endif /* USE_FULL_ASSERT */

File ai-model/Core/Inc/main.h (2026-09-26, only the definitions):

#define B1_Pin GPIO_PIN_13
#define B1_GPIO_Port GPIOC
#define USART_TX_Pin GPIO_PIN_2
#define USART_TX_GPIO_Port GPIOA
#define USART_RX_Pin GPIO_PIN_3
#define USART_RX_GPIO_Port GPIOA
#define LD2_Pin GPIO_PIN_5
#define LD2_GPIO_Port GPIOA
#define TMS_Pin GPIO_PIN_13
#define TMS_GPIO_Port GPIOA
#define TCK_Pin GPIO_PIN_14
#define TCK_GPIO_Port GPIOA

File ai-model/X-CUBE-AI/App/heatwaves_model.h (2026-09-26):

/**
  ******************************************************************************
  * @file    heatwaves_model.h
  * @author  AST Embedded Analytics Research Platform
  * @date    2026-03-10T14:51:04-0400
  * @brief   AI Tool Automatic Code Generator for Embedded NN computing
  ******************************************************************************
  * @attention
  *
  * Copyright (c) 2026 STMicroelectronics.
  * All rights reserved.
  *
  * This software is licensed under terms that can be found in the LICENSE file
  * in the root directory of this software component.
  * If no LICENSE file comes with this software, it is provided AS-IS.
  ******************************************************************************
  */
#ifndef AI_HEATWAVES_MODEL_H
#define AI_HEATWAVES_MODEL_H

#include "heatwaves_model_config.h"
#include "ai_platform.h"

/******************************************************************************/
#define AI_HEATWAVES_MODEL_MODEL_NAME          "heatwaves_model"
#define AI_HEATWAVES_MODEL_ORIGIN_MODEL_NAME   "heatwave_model_updated"

/******************************************************************************/
#define AI_HEATWAVES_MODEL_ACTIVATIONS_ALIGNMENT   (4)
#define AI_HEATWAVES_MODEL_INPUTS_IN_ACTIVATIONS   (4)
#define AI_HEATWAVES_MODEL_OUTPUTS_IN_ACTIVATIONS  (4)

/******************************************************************************/
#define AI_HEATWAVES_MODEL_IN_NUM        (1)

AI_DEPRECATED
#define AI_HEATWAVES_MODEL_IN \
  ai_heatwaves_model_inputs_get(AI_HANDLE_NULL, NULL)

#define AI_HEATWAVES_MODEL_IN_SIZE { \
  AI_HEATWAVES_MODEL_IN_1_SIZE, \
}
#define AI_HEATWAVES_MODEL_IN_SIZE_BYTES { \
  AI_HEATWAVES_MODEL_IN_1_SIZE_BYTES, \
}
#define AI_HEATWAVES_MODEL_IN_1_FORMAT      (AI_BUFFER_FORMAT_FLOAT)
#define AI_HEATWAVES_MODEL_IN_1_CHANNEL     (5)
#define AI_HEATWAVES_MODEL_IN_1_SIZE        (5)
#define AI_HEATWAVES_MODEL_IN_1_SIZE_BYTES  (20)

/******************************************************************************/
#define AI_HEATWAVES_MODEL_OUT_NUM       (1)

AI_DEPRECATED
#define AI_HEATWAVES_MODEL_OUT \
  ai_heatwaves_model_outputs_get(AI_HANDLE_NULL, NULL)

#define AI_HEATWAVES_MODEL_OUT_SIZE { \
  AI_HEATWAVES_MODEL_OUT_1_SIZE, \
}
#define AI_HEATWAVES_MODEL_OUT_SIZE_BYTES { \
  AI_HEATWAVES_MODEL_OUT_1_SIZE_BYTES, \
}
#define AI_HEATWAVES_MODEL_OUT_1_FORMAT      (AI_BUFFER_FORMAT_FLOAT)
#define AI_HEATWAVES_MODEL_OUT_1_CHANNEL     (1)
#define AI_HEATWAVES_MODEL_OUT_1_SIZE        (1)
#define AI_HEATWAVES_MODEL_OUT_1_SIZE_BYTES  (4)

/******************************************************************************/
#define AI_HEATWAVES_MODEL_N_NODES (4)


AI_API_DECLARE_BEGIN

/*!
 * @defgroup heatwaves_model
 * @brief Public neural network APIs
 * @details This is the header for the network public APIs declarations
 * for interfacing a generated network model.
 * @details The public neural network APIs hide the structure of the network
 * and offer a set of interfaces to create, initialize, query, configure, 
 * run and destroy a network instance.
 * To handle this, an opaque handler to the network context is provided 
 * on creation.
 * The APIs are meant as stadard interfaces for the calling code; depending on
 * the supported platforms and the models, different implementations could be
 * available.
 */

/******************************************************************************/
/*! Public API Functions Declarations */

/*!
 * @brief Get network library info as a datastruct.
 * @ingroup heatwaves_model
 * @param[in] network: the handler to the network context
 * @param[out] report a pointer to the report struct where to
 * store network info. See @ref ai_network_report struct for details
 * @return a boolean reporting the exit status of the API
 */
AI_DEPRECATED
AI_API_ENTRY
ai_bool ai_heatwaves_model_get_info(
  ai_handle network, ai_network_report* report);



/*!
 * @brief Get network library report as a datastruct.
 * @ingroup heatwaves_model
 * @param[in] network: the handler to the network context
 * @param[out] report a pointer to the report struct where to
 * store network info. See @ref ai_network_report struct for details
 * @return a boolean reporting the exit status of the API
 */
AI_API_ENTRY
ai_bool ai_heatwaves_model_get_report(
  ai_handle network, ai_network_report* report);


/*!
 * @brief Get first network error code.
 * @ingroup heatwaves_model
 * @details Get an error code related to the 1st error generated during
 * network processing. The error code is structure containing an 
 * error type indicating the type of error with an associated error code
 * Note: after this call the error code is internally reset to AI_ERROR_NONE
 * @param network an opaque handle to the network context
 * @return an error type/code pair indicating both the error type and code
 * see @ref ai_error for struct definition
 */
AI_API_ENTRY
ai_error ai_heatwaves_model_get_error(ai_handle network);


/*!
 * @brief Create a neural network.
 * @ingroup heatwaves_model
 * @details Instantiate a network and returns an object to handle it;
 * @param network an opaque handle to the network context
 * @param network_config a pointer to the network configuration info coded as a 
 * buffer
 * @return an error code reporting the status of the API on exit
 */
AI_API_ENTRY
ai_error ai_heatwaves_model_create(
  ai_handle* network, const ai_buffer* network_config);


/*!
 * @brief Destroy a neural network and frees the allocated memory.
 * @ingroup heatwaves_model
 * @details Destroys the network and frees its memory. The network handle is returned;
 * if the handle is not NULL, the unloading has not been successful.
 * @param network an opaque handle to the network context
 * @return an object handle : AI_HANDLE_NULL if network was destroyed
 * correctly. The same input network handle if destroy failed.
 */
AI_API_ENTRY
ai_handle ai_heatwaves_model_destroy(ai_handle network);


/*!
 * @brief Initialize the data structures of the network.
 * @ingroup heatwaves_model
 * @details This API initialized the network after a successfull
 * @ref ai_heatwaves_model_create. Both the activations memory buffer 
 * and params (i.e. weights) need to be provided by caller application
 * 
 * @param network an opaque handle to the network context
 * @param params the parameters of the network (required). 
 * see @ref ai_network_params struct for details
 * @return true if the network was correctly initialized, false otherwise
 * in case of error the error type could be queried by 
 * using @ref ai_heatwaves_model_get_error
 */
AI_API_ENTRY
ai_bool ai_heatwaves_model_init(
  ai_handle network, const ai_network_params* params);
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

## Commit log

2026-09-26 Add heatwave capstone poster
2026-09-26 Add HeatWave project source files
    [Aosong_DHT11_5.5x12.0_P2.54mm.SLDPRT, B3F-1000--3DModel-STEP-418109.SLDPRT, BLUENRG-M0A.SLDPRT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]

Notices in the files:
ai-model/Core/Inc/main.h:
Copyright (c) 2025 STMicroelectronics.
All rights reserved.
